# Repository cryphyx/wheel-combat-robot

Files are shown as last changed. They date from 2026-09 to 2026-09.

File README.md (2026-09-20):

# 轮式自主格斗机器人：结构设计工作记录

这是一个参赛机器人的**在研结构展示**。仓库收录当前工作模型中的自制打印结构件、装配预览和验证状态。它不是可直接生产的完整整车，也没有经过实车比赛验证。

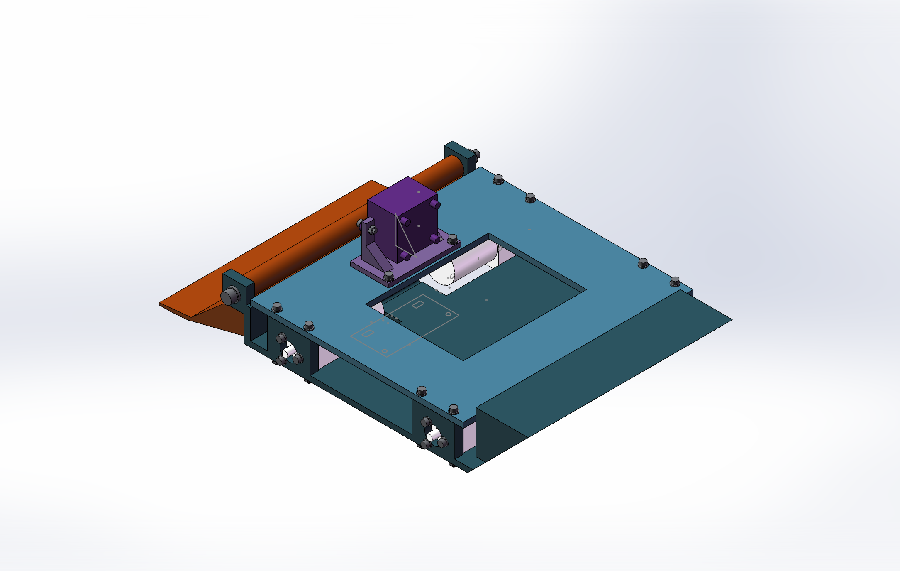
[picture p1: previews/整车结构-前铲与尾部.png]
当前整车结构预览


## 设计内容

- 双层底盘、下沉电机安装位与一体电机座。
- 手动翻转的整块塑料前铲及实体承力止挡。
- 底盘一体尾坡、摄像头一体安装座、电池压梁与传感器夹持座。
- 非黑色塑料打印结构方案；紧固件仅作连接使用。

`cad-parts/` 提供这些零件的原生 SolidWorks `.SLDPRT` 文件。`previews/` 是工作装配的截图。完整装配涉及统一部件模型和仍在核对的接口，本仓库暂未提供可宣称装配完成的 `.SLDASM`。

## 当前状态（2026-09-17）

工作装配已纳入四轮、控制系统和部分传感器，但仍缺四只边缘光电；轮组与联轴器转动时存在待修正的微量干涉，后向红外光轴也需调整。轮胎外径、轮毂锁紧、传感器实物尺寸和整车质量等仍需实测。详细记录见 [续接核查](docs/续接核查与待确认.md)和[逐只传感器核查](docs/逐只传感器核查.md)。

**不要根据此仓库直接打印或参赛。** CAD 干涉检查和渲染图不能证明能上台、能检测边缘或符合全部比赛规则。

本方案研究过第三方设计报告中的双层底盘与尾部路径；该报告及其图片不在仓库中。仓库展示的是当前团队的建模和验证工作，不将参考报告归为原创成果。

## 后续工作

1. 实测统一轮胎、联轴器和全部传感器接口。
2. 修正轮组干涉和后向红外布置，补齐边缘检测。
3. 核查比赛态与收纳态外廓、质量、重心、连续运动扫掠及真实场地测试。

仓库未附开源许可证；如需复用模型，请先联系作者。

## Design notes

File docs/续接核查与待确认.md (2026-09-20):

# 报告方案续接核查

2026-09-17。当前只完成续接核查，未完成整车设计，不得作为打印或参赛放行文件。

## 基线及上次实际执行

工作装配：报告方案-双层底盘重建/报告方案-底盘工作装配.SLDASM，磁盘最后保存时间2026-09-17 10:56。继续报告方案，不使用R2及旧版作为设计基础。未重建底盘、前铲、尾坡、电机、摄像头或电控。

已读取STATE.md；其99组件记录早于当前装配，不能作为当前数量。上次任务的SensorRunner.exe photo实际exitCode=0，输出“四路水平光电固定 INTERFERENCE_COUNT=0”。实时COM核查证实四个M18光电及8个配套薄螺母已在装配，上/下板安装座已保存，禁止再次运行该非幂等增量命令。

## 当前CAD核查结果

- 282组件实例，43个不同引用文件，全部组件模型已解析；未发现相同文件加相同变换的重复实例。
- 灰度4、红外5、水平光电4、摄像头1。尚缺边缘光电4；不能宣称8光电完成。
- 静态实体干涉0，检查包含隐藏实体；此结论只适用于当前未补齐的装配。
- 实体极值包络X=-198..145、Y=-137..137、Z=0..104 mm，即343×274×104 mm。
- CAD轮胎直径65 mm；四轮最低点Z=0；前铲最低点Z=1.2 mm；灰度本体最低点Z=4 mm。真实轮胎尺寸和压缩量尚未确认，因此不能给出实车离地间隙保证。
- SolidWorks当前质量属性1.936489712 kg，质心(-13.2806,0.6691,46.9073) mm。材料密度、打印填充、实物硬件重量及线束尚未核实，该值只能标注为未校准CAD属性，不能用于4 kg合规判定或后轴静载结论。
- 前铲0..90度每5度的19点复核均为0干涉，已恢复原位，旧检查记录保留。离散检查不等于连续扫掠，也不包含尚未加入的4个边缘光电。
- 四轮圆柱回转包络与一般结构包络相离；每轮3个电机法兰螺钉落入保守包络候选，须结合四轮离散转动复核.txt看实际结果。不能把包络候选当作真实干涉。
- 初始282组件中271个为Fixed，11个非Fixed（摄像头安装标准件8个、前铲与勾面3个）；非Fixed件是否完全配合约束尚待核对。固定坐标只说明CAD姿态，不能证明机械接口、防松、真实锁紧与运动配合已完成；轮组需要最终真实转动副及锁紧方式核对。

## 规则复核

已完整读取指定正式PDF的14页。允许：规定控制器、BDMC及配套电机、三线传感器和规定电池；非黑色不透明塑料结构；橡胶轮胎直径不超过68 mm；连接紧固件按规则例外使用。禁止：金属铲体或刃口、黑色/透明结构、贴二维码、危险攻击装置、对外粘附、场外遥控。出发区投影不超过300×300 mm，重量不超过4 kg；不得依赖5%误差。

当前展开长度343 mm，不能以此姿态直接证明出发区尺寸合规。手动折叠与展开时机仍需结合规则2.4及2.5确认；不能把折叠尺寸合规自动视为开赛程序合规。

需要实测/确认：轮胎外径、轮毂锁紧接口、现用光电型号与真实外形、材料/颜色、最终重量与线束。按项目长期指令，轮胎实测是继续新增建模的前置条件。

## 感知接口与问题

实际.robot_profile=xin。robot_config.py：gray(lf,rf,lb,rb)=ADC(0,1,2,3)；ir(l,r,lf,rf,b)=ADC(4,6,5,7,8)；edge(lf,rf,lb,rb)=IO(5,6,0,4)；stage(l,r,f,b)=IO(1,3,2,7)。robot_stage.py区分边缘检测与接触检测，后接触参与转向逻辑。禁止把水平前光电当作下视传感器或新增双后红外通道。

后向红外本体Z=77.5..103.5 mm，前向两个红外本体Z=73.5..99.5 mm；现有光轴水平。平地姿态下光轴高于60 mm台沿，无法按报告中的上下两类传感器高度差直接判断台沿。后向红外需要重新核对低位光路、尾坡遮挡和撞台保护，保留当前ADC8。

M18源模型主要圆柱直径17.8 mm，包含尾部出线凸起后的完整轴向包络77.5 mm；旧“58 mm包络”记录不能代替当前引用的完整实体。螺母规格目前明确标注待实物复核，须确认螺纹、可用夹持长度和光学端。

前铲尖X=-198 mm。35..45 mm后方对应X=-163..-153 mm，按当前连续斜面草图截面，上下斜面之间的竖向厚度约5.98..12.04 mm。该数据用于安装方案筛查，不单独证明斜置圆柱不可装入。必须同时验证倾斜本体、最小下视窗口、上攻击面保留厚度、固定在主底盘的支架以及整个翻转避让，不能简单在这个薄区打M18贯通孔。

## 增量方案与删减审计

保留：已建双层底盘、四电机及轮组、整体前铲、硬止挡、一体尾坡、摄像头及双耳座、电控与现有灰度夹座。未发现文件损坏，不执行重建。

待局部修正：前/后向红外的有效台沿检测高度；新增四个边缘光电的实体安装、光路及线束；全部固定件的真实接口及运动配合。

前缘方案A：保持整块楔体与连续上表面，主底盘固定两只向前下方斜置的现用光电，仅增加必要向下光路与扫掠避让；需实体包络及折叠复核后才能接受。
方案B：同通道现有光电后置，通过更长向下光路通道观察前方；零件位置较靠后但通道更长，易遮光，并不自动满足铲尖后35..45 mm安装要求。未证明视场前不能冻结。
否决：把传感器固定在活动铲上、开穿上攻击面、改变8路IO数量、无安装面的悬空件、靠细长外挂支架解决问题。

## 未完成与下一步

等待实物尺寸后，在独立正式目录中复制并重定向引用，继续增量建模，不覆盖当前基线。补齐4个边缘光电，修正红外光路，完成真实紧固、走线和维护空间，再做全装配干涉、轮胎/前铲扫掠、60 mm台阶三姿态几何与质量重心复核，最后工程图及保存关闭重开验证。

尚未生成正式整车V1、完整工程图、60 mm台阶三姿态模型或整车通过报告。现有七张视图是282组件状态的核查预览，不是完成态。不能仅据CAD声称登台成功、耐撞、能掀车或传感器实场可靠。

## 四轮运动检查补充

单独转动车轮而不转六角联轴器的检查会制造不符合传动关系的六角相对运动，因此“四轮离散转动复核.txt”仅保留为诊断记录，不能用于真实轮组放行。正式判读以“四轮及联轴器同步转动复核.txt”为准。

同步转动中发现真实间隙问题：部分角度的六角联轴器与电机法兰M3接口平垫圈相交，每处约0.001367 mm³；静态0度未出现。涉及每个电机三只垫圈，共12个接口。名义孔圆半径10.4 mm、垫圈半径3.5 mm、六角最大半径约6.9282 mm，最不利径向余量约-0.0282 mm，解释了微小重叠。即使体积很小也不能默认忽略，尚未按实物公差放行。

后续可局部调整适用垫圈外径/紧固组合，但必须保留打印件承压面积、螺钉夹持与工具空间，并使用已核实的真实标准件。不能为了显示零干涉简单隐藏垫圈，也不能把联轴器固定不转来通过检查。

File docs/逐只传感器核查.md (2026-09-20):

# 全部传感器安装核查状态

坐标单位mm；X负为前，Y负为左，Z向上。以下逐只记录已知证据及尚未验证项，不将静态零干涉等同于光路通过。名义型号尚待实物确认，所有有效视场、插头弯折及阈值均须实测。

|传感器|通道|现有安装与包络|光路/碰撞/维护审查|
|---|---|---|---|
|左前灰度|ADC0|X -88..-40，Y -23.35..-4.65，Z4..14；下板夹座，两端M3|本体朝下；静态不碰电池紧固件；底部夹持唇是否遮住发射/接收区待实物光窗定位；需从下方拆换|
|右前灰度|ADC1|X -88..-40，Y4.65..23.35，Z4..14；同型夹座|同上，左右独立夹座及紧固件；最小实体高度4mm，不代表有效测距高度|
|左后灰度|ADC2|X40..88，Y -23.35..-4.65，Z4..14|同型真实夹座；尾部倾斜姿态与地面撞击尚未验证|
|右后灰度|ADC3|X40..88，Y4.65..23.35，Z4..14|同上；接插件和排线不得进入后轮旋转空间|
|左红外|ADC4|X -22.45..22.45，Y -109..-95，Z24.5..50.5；上板向下座，37.4孔距M3|轴向-Y；处于60mm台沿以下；名义光路向外，需实测视场和轮胎斜向遮挡|
|右红外|ADC6|X -22.45..22.45，Y95..109，Z24.5..50.5；对称座|轴向+Y；静态无干涉；轮侧保护距离与接插件需复核|
|左前红外|ADC5|X -105..-91，Y -100.45..-55.55，Z73.5..99.5；上板座M3|轴向-X；光轴高于台面60mm，不能作为平地台沿探测已通过；折铲19姿态无实体干涉，视场另检|
|右前红外|ADC7|X -105..-91，Y55.55..100.45，Z73.5..99.5；上板座M3|轴向-X；同上|
|后红外|ADC8|X96..110，Y -92.45..-47.55，Z77.5..103.5；上板后座M3|轴向+X；明显高于60mm台沿；必须修正或明确与其它传感器的功能分工，不能沿用报告的双后测距解释|
|左水平光电|IO1|X39.1..56.9，Y -107.5..-30，Z69.1..86.9；上板座＋双M18薄螺母|轴向-Y；螺母和螺纹为名义接口待复核；线尾朝内，真实插拔空间未核实|
|右水平光电|IO3|X39.1..56.9，Y30..107.5，Z69.1..86.9；对称座|轴向+Y；同上|
|前水平光电|IO2|X -111.5..-34，Y31.1..48.9，Z63.1..80.9；上板前座＋双螺母|轴向-X；不是边缘光电；当前位于上板前部而非低位嵌入薄铲；需要复核保护轮廓与用户低位要求|
|后水平光电|IO7|X60..137.5，Y59.1..76.9，Z69.1..86.9；尾坡上部实体座＋双螺母|轴向+X；比尾坡后端X145内缩7.5mm，水平状态不先碰60mm台沿；倾斜登台碰撞仍待三姿态实体检查|
|摄像头|视觉|X -83..-50，Y -26.76..26.76，Z66..104；双耳一体座及M3|已实际固定；前铲离散翻转不碰本体；光轴、前铲在图像中的遮罩、线尾弯折需要成像与实物复核|
|左前边缘光电|IO5|未安装|必须固定主底盘坐标系；前铲后35..45区域光路和整段翻转避让均未完成|
|右前边缘光电|IO6|未安装|同上，左右对称且向中部收拢|
|左后边缘光电|IO0|未安装|应斜下，具备尾坡碰撞保护且不遮蔽光路；实体安装与检修入口未完成|
|右后边缘光电|IO4|未安装|同上，禁止成为后冲第一接触件|

全部已有组件的实体引用正常，当前静态零干涉。上述所有“待复核/未完成”均是建模及交付门槛，不能省略后标为完成。

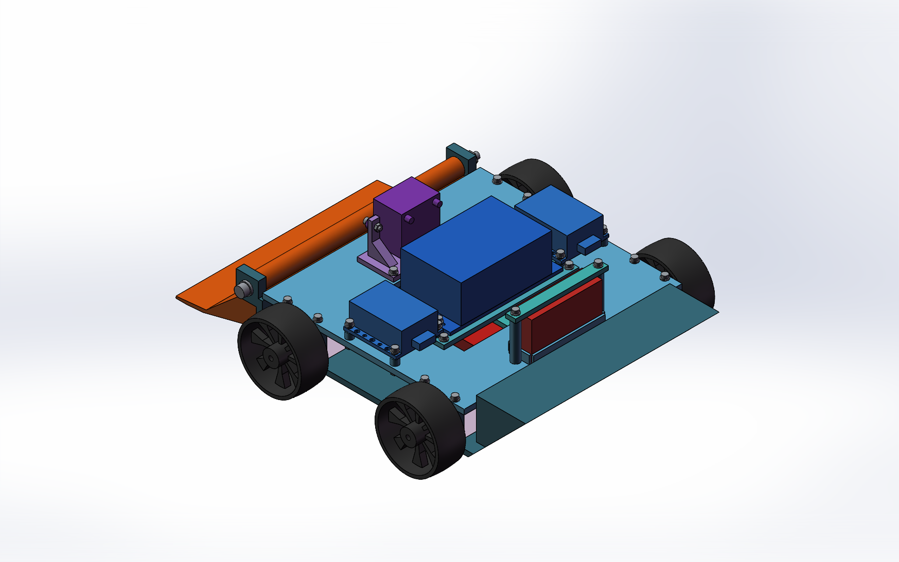
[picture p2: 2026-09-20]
previews/四轮与控制系统.png

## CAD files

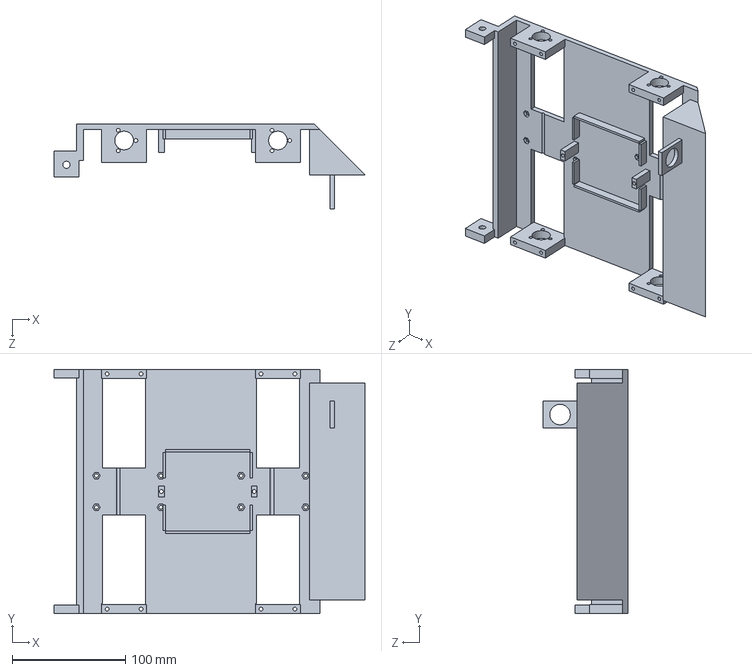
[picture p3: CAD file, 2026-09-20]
cad-parts/01-下底板-四电机避让与一体座.SLDPRT
275.0 x 216.0 x 75.0 mm

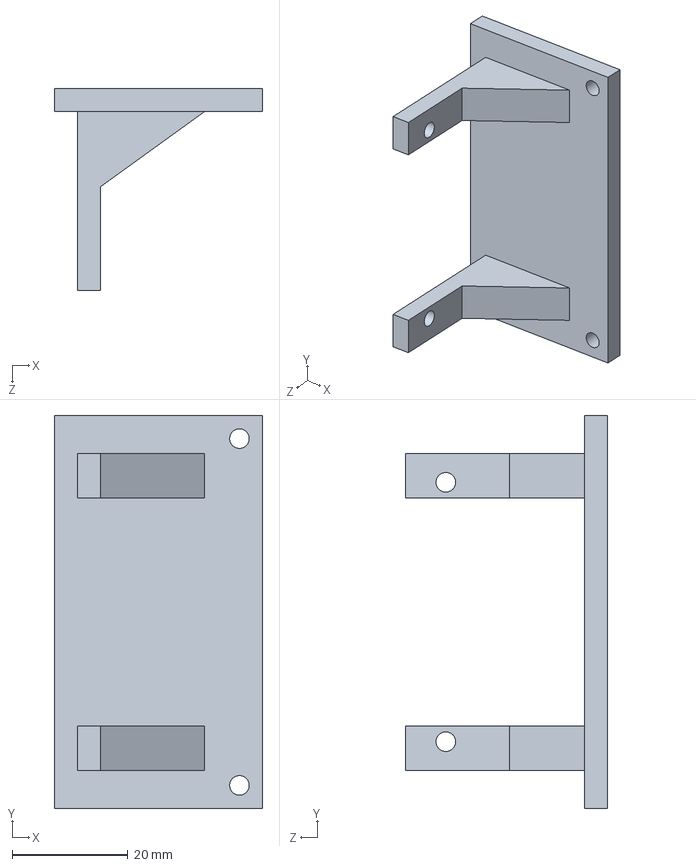
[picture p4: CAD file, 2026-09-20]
cad-parts/03-摄像头-直接双耳一体座.SLDPRT
36.0 x 68.0 x 35.0 mm

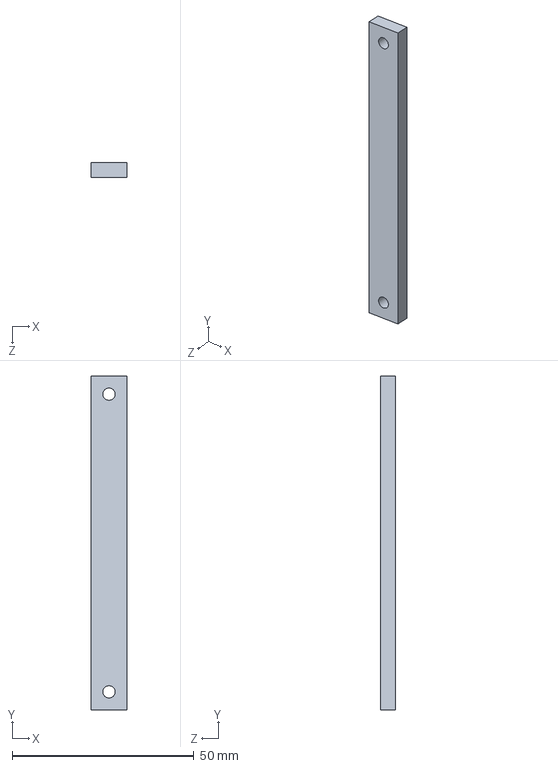
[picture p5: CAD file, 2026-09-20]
cad-parts/09-控制电池单件压梁.SLDPRT
10.00 x 92.0 x 4.00 mm

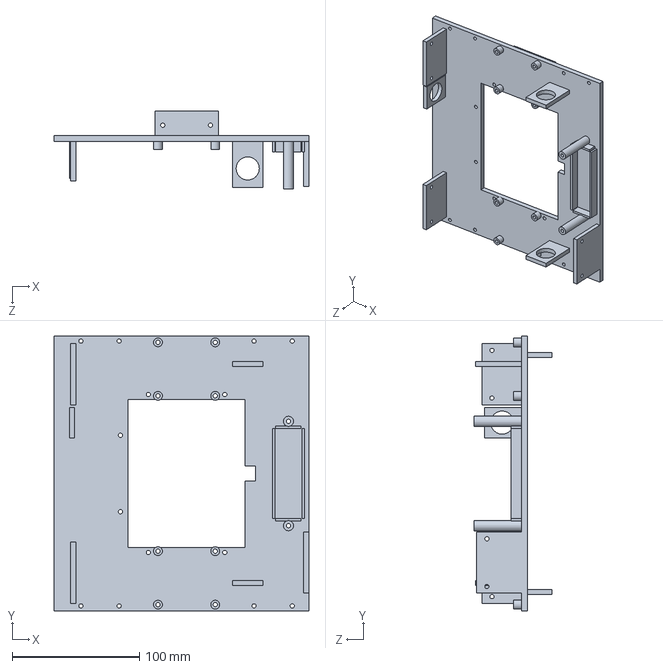
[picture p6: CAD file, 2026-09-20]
cad-parts/02-上总板-中央设备开口.SLDPRT
200.0 x 216.0 x 61.0 mm

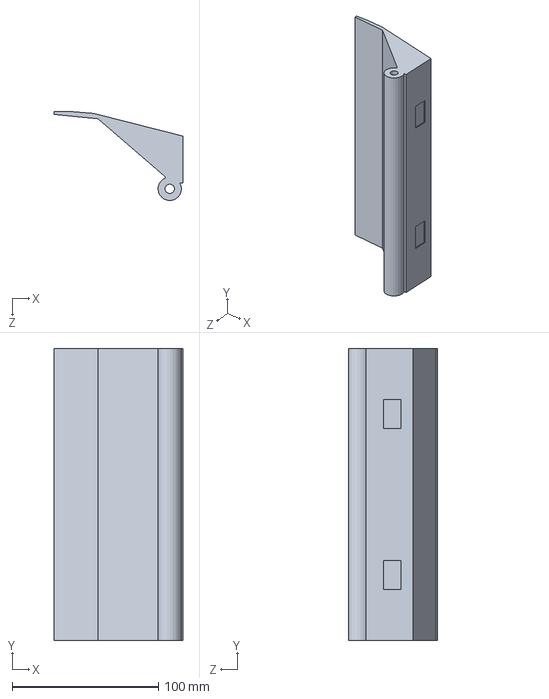
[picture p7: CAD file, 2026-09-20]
cad-parts/04-整块渐进双坡前铲-手动翻转.SLDPRT
88.0 x 199.4 x 60.8 mm

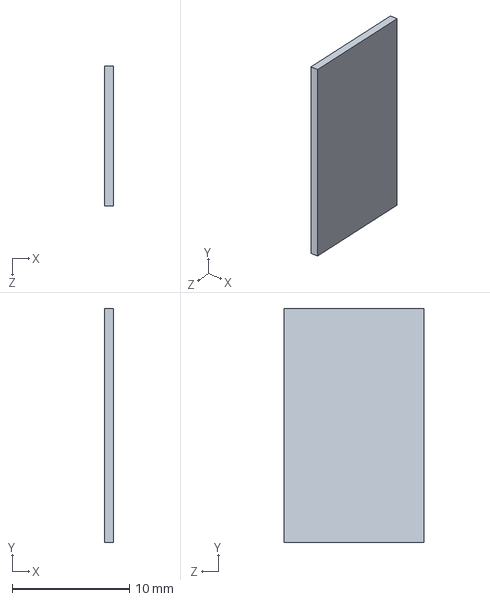
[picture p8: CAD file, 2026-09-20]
cad-parts/05-魔术贴毛面.SLDPRT
0.8 x 20.0 x 12.0 mm

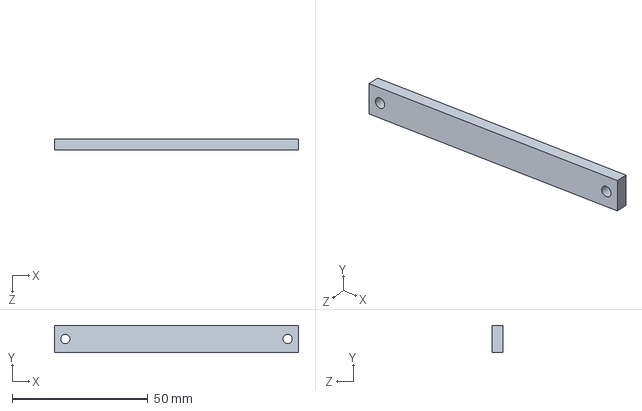
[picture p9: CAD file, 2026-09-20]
cad-parts/07-低置动力电池-单件压梁.SLDPRT
90.0 x 10.0 x 4.00 mm

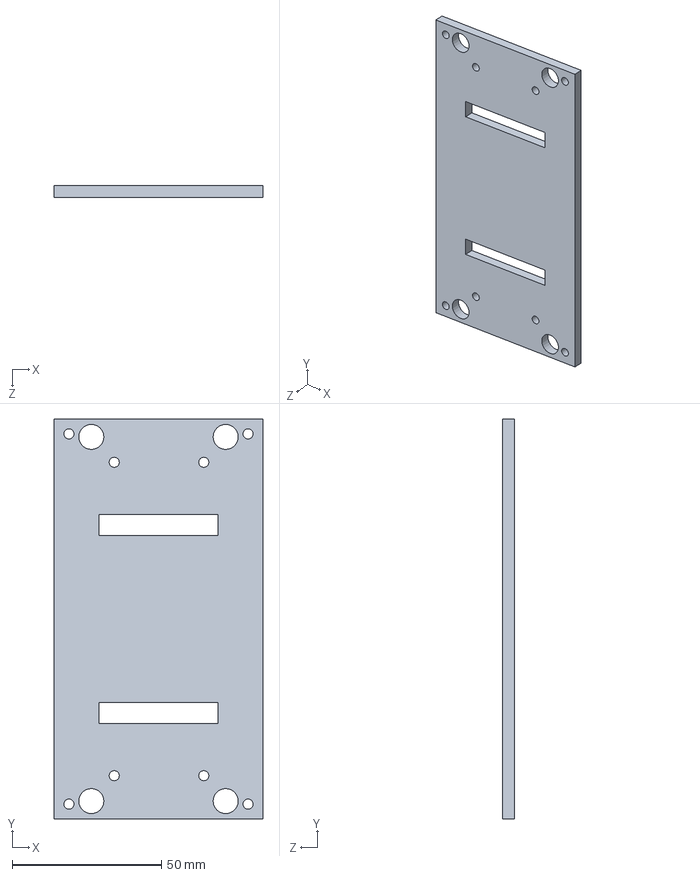
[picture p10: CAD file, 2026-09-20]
cad-parts/08-中央可拆主控托板.SLDPRT
70.0 x 134.0 x 4.00 mm

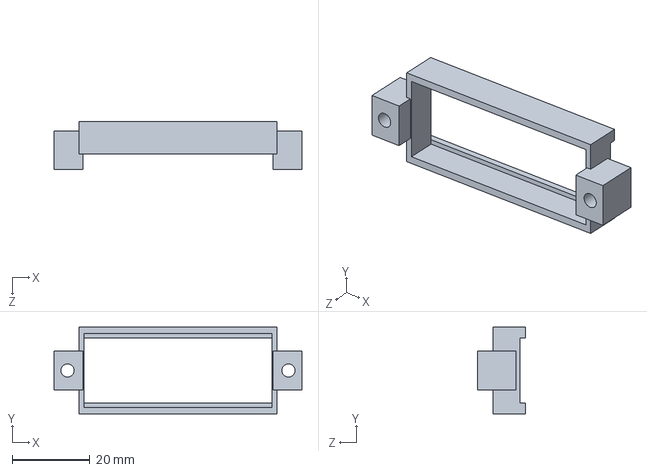
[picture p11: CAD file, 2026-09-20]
cad-parts/10-灰度传感器边缘夹持座.SLDPRT
64.0 x 22.4 x 12.5 mm

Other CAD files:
cad-parts/06-魔术贴勾面.SLDPRT

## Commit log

2026-09-20 Add validation notes and sensor audit
2026-09-20 Add work assembly previews
2026-09-20 Add native SolidWorks work parts
    [01-下底板-四电机避让与一体座.SLDPRT, 02-上总板-中央设备开口.SLDPRT, 03-摄像头-直接双耳一体座.SLDPRT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]
